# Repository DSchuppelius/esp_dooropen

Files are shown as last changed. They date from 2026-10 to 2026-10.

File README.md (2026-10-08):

# esp_dooropen

SIP-Türöffner für **ESP32 DevKit (WROOM-32)**, **WT32-ETH01** (ESP32 mit Ethernet) oder
**ESP8266 HW-364A** (NodeMCU mit fest verbautem OLED). Klingelt es, ruft der ESP per SIP ein Telefon an; mit **`*`** (oder einem Code) am
Telefon, über die **Weboberfläche**, per **Taster** oder aus **Home Assistant** wird die
Tür geöffnet.

Die Zielplattform wird über die PlatformIO-Umgebung gewählt (siehe
[Bauen & Flashen](#bauen--flashen-platformio)); der Code passt sich per
Präprozessor-Weiche automatisch an.

## Funktionen

- **Klingel-Eingang** (potentialfreier Kontakt, entprellt) mit Zähler und Hinweis
  „Es klingelt!“ im Web, auf dem Display und in Home Assistant.
- **Türsummer** über ein Relais, Dauer einstellbar (1–30 s). Ein Hardware-Timer
  schaltet das Relais auch dann pünktlich ab, wenn das Programm gerade hängt.
- **SIP-Anruf beim Klingeln** (getestet mit Asterisk, REGISTER mit Digest-Auth
  inkl. `qop=auth`/`opaque`, auch LANCOM-kompatibel):
  - **Rufkette**: mehrere Nummern nacheinander (z. B. `100, 101`), bis jemand abhebt,
  - nach dem Abheben ein Piepton im Hörer (G.711 A-law/µ-law),
  - **`*` am Telefon** (DTMF per RFC 4733 oder SIP INFO) öffnet die Tür und legt auf –
    oder ein **Öffnen-Code** (z. B. `1234`), dann bleibt das Gespräch 30 s offen,
  - wird nicht abgehoben, wird der Anruf nach 15 s per `CANCEL` zurückgezogen,
  - **SIP-Status im Klartext** und Ergebnis des letzten Anrufs,
  - **robust im WLAN**: `INVITE` (auch mit Digest), `CANCEL`, `BYE` und `REGISTER`
    werden bei Paketverlust wiederholt (RFC 3261); eine gescheiterte Erneuerung
    meldet erst „abgemeldet“, wenn die Anmeldung wirklich abläuft. Kopfzeilen in
    jeder Schreibweise und Kurzform (`i:`, `f:` …) werden verstanden; ein Server als
    Hostname wird einmal je Anmeldung aufgelöst (folgt auch einem DHCP-Wechsel).
- **Klingeln per Anruf**: Eine TK-Anlage (z. B. OpenCom) ruft beim Klingeln den
  Türöffner an – er nimmt nicht ab und wertet das als Klingeln. Ganz ohne Verdrahtung.
- **Anrufe an den Türöffner** (optional): Wer die Nebenstelle des Türöffners anruft,
  hört einen kurzen Ton und tippt den Öffnen-Code oder einen **Gästecode**
  (bis zu 5, mit Name, Ablaufdatum und „einmalig“). Nach mehreren falschen Codes
  werden Anrufe für 15 min gesperrt.
- **Weboberfläche** mit hellem/dunklem Design, großem Öffnen-Knopf mit
  Countdown-Ring, Statuskacheln, Test-Anruf und Ton-Benachrichtigung im Browser.
- **Home Assistant** per MQTT mit Auto-Discovery (Schloss, Button, Klingel-Ereignis,
  Sensoren, letztes Ereignis, Einstellungen).
- **OLED SSD1306** (optional) zeigt IP, Signal- und Summer-Status; wird kein
  Display gefunden, läuft alles ohne.
- **Status-LED** mit Blinkmustern (Summer, WLAN-Einrichtung, kein WLAN, SIP fehlt).
- **Taster** vor Ort: Klingel-Taster (wirkt wie Klingeln) und Summer-Taster (öffnet).
- **Zweites Relais** (Tor, Garage, zweite Tür) mit eigenem Knopf, eigener Dauer und
  wahlweise auch für den Tür-Zugang.
- **Tastenfeld / RFID-Leser** (Wiegand, ESP32): Öffnen-Code oder Gästecode am
  Tastenfeld, Karten/Chips mit Namen; Sperre nach Fehlversuchen.
- **Telegram-Bot** (ESP32): Klingel-Mitteilung mit Knopf **„Öffnen“**, Befehle
  `/status` und `/oeffnen` – auch unterwegs, ohne Portfreigabe.
- **Apple Home** (HomeKit, eigene ESP32-Variante): Türschloss mit Türklingel direkt in
  der Home-App, ohne Home Assistant.
- **Zugänge** mit eigener Anmeldeseite: Admin (alles) und Tür-Zugang (nur öffnen und
  Verlauf sehen, z. B. für den Kunden; ohne Tür-Passwort ist die Tür offen), dazu bis
  zu 8 **weitere Benutzer** mit Rolle und Zeitfenster – der Verlauf zeigt, wer
  geöffnet hat. Ohne Admin-Passwort warnt die Oberfläche deutlich.
- **Firmware-Update über WLAN**: per Browser-Upload oder aus PlatformIO (OTA, nur
  mit Admin-Passwort).
- **Erreichbar unter `http://tueroeffner.local`** (mDNS).
- **Verlauf** der letzten 30 Ereignisse mit Uhrzeit (NTP) und Detail (z. B. Name des
  Gästecodes, Nummer des Anrufers, Benutzer); **übersteht Neustarts**. Dazu ein langer
  Verlauf (mehrere Tausend Einträge) im Flash, als **CSV** herunterladbar.
- **Nachtruhe**: in einem Zeitfenster beim Klingeln nicht anrufen.
- **Praxis-Modus**: an gewählten Wochentagen in **zwei Zeitfenstern** öffnet Klingeln
  die Tür automatisch (ohne Anruf); **gesetzliche Feiertage je Bundesland** werden
  automatisch berücksichtigt, weitere **Ausnahmetage** (Urlaub) einstellbar. Bei
  Fenstern über Mitternacht (z. B. 22–2 Uhr) gehört der Teil nach Mitternacht zum
  Vortag (Wochentag, Feier- und Ausnahmetag des Vortags).
- **Uhrzeit** per NTP: `pool.ntp.org`, ersatzweise das **Gateway** (Router oder
  TK-Anlage, z. B. FRITZ!Box „Zeitserver im Heimnetz bereitstellen“) und
  `de.pool.ntp.org`. So laufen Praxis-Modus, Nachtruhe und Zeitfenster auch ohne
  Internet, wenn der Router NTP anbietet. Ohne gültige Uhrzeit sind Praxis-Modus und
  Nachtruhe aus.
- **Türkontakt** (Reed): Tür offen/zu im Web und in Home Assistant, Meldung, wenn die
  Tür zu lange offen steht, und Prüfung, ob nach dem Summer wirklich jemand
  hereinkam („Tür nach Summer geöffnet“ / „Summer, Tür blieb zu“).
- **Push-Mitteilungen ohne Home Assistant** über **ntfy** oder **Telegram**
  (Klingeln, Öffnen, Tür zu lange offen, Sperre nach falschen Codes).
- **Syslog**: Meldungen und Ereignisse an einen Syslog-Server (Fehlersuche aus der Ferne).
- **Ethernet** statt WLAN mit dem WT32-ETH01 (z. B. per PoE versorgt).
- **Selbstheilung**: Ist das WLAN weg, verbindet der ESP jede Minute neu; als letzte
  Stufe Neustart nach 30 min. Ethernet: Neustart nur, wenn ein Link da ist, aber
  10 min keine IP kommt (bei gezogenem Kabel nicht). Außerdem Neustart, wenn der
  Speicher knapp oder zerstückelt ist oder das Programm hängt (Watchdog auf beiden
  Boards); der Grund des letzten Starts wird angezeigt.
- **Neue IP per DHCP** wird erkannt, SIP meldet sich dann sofort neu an.
- **Sicherung**: alle Einstellungen als Datei herunterladen und wieder einspielen.
- **Feste IP-Adresse** wahlweise statt DHCP (vor dem Speichern geprüft: Maske,
  Gateway im selben Netz, keine Netz-/Broadcast-Adresse – gegen Aussperren).
- **Sperre gegen Sturmklingeln**: Klingeln innerhalb von 5 s löst keinen neuen
  Anruf aus.
- **WiFiManager**: Ohne gespeicherte Zugangsdaten öffnet der ESP das
  passwortgeschützte WLAN `Tueroeffner-Setup` zum Eintragen – **ohne zu blockieren**:
  Klingel, Taster und Summer funktionieren währenddessen weiter. Ist das bekannte WLAN
  nur weg (z. B. startet der Router nach einem Stromausfall langsamer als der ESP),
  verbindet er weiter und öffnet die Einrichtung erst nach 15 min ohne Verbindung –
  dann für 5 min, während die Verbindung zum WLAN weiter versucht wird.
- Einstellungen, Zähler und Verlauf liegen im **LittleFS** (Zähler/Verlauf werden
  höchstens alle 5 min geschrieben, der lange Verlauf gebündelt höchstens einmal pro
  Minute, um den Flash zu schonen; vor Neustart und Update wird alles gesichert).
  Gespeichert wird geprüft über eine Hilfsdatei – bei vollem oder defektem Speicher
  bleibt die alte Datei, die Oberfläche meldet den Fehler. Für die Einstellungen bleibt
  immer Platz frei (notfalls wird der ältere Verlauf gelöscht). Wurde der Speicher beim
  Start formatiert oder ist er nicht verfügbar, zeigt die Oberfläche eine Warnung.
  Ereignisse ohne Uhrzeit (kein NTP) bleiben erhalten und erscheinen als „ohne Uhrzeit“.

## Verdrahtung

### ESP32 DevKit (WROOM-32)

Hier gelten echte GPIO-Nummern. Ein OLED ist optional.

| Funktion | Pin | Hinweis |
|---|---|---|
| Relais S (Signal) | GPIO26 | schaltet das Relais (active-high) |
| Relais + / - | 5V / GND | Relais-Modul aus 5 V versorgen |
| Klingel-Kontakt | GPIO27 | eine Ader hier, andere Ader an GND |
| Klingel-Taster | GPIO32 | Taster gegen GND, wirkt wie Klingeln |
| Summer-Taster | GPIO33 | Taster gegen GND, öffnet die Tür |
| Türkontakt (optional)| GPIO25 | Reed-Kontakt gegen GND, geschlossen = zu |
| Status-LED | GPIO2 | onboard oder extern, siehe [Status-LED](#status-led) |
| OLED SDA (optional)  | GPIO21 | nur falls ein Display genutzt wird |
| OLED SCL (optional)  | GPIO22 | nur falls ein Display genutzt wird |
| Relais 2 (optional)  | GPIO13 | zweites Relais (Tor, Garage …) |
| Wiegand D0 (optional)| GPIO18 | Tastenfeld/RFID-Leser, siehe unten |
| Wiegand D1 (optional)| GPIO19 | Tastenfeld/RFID-Leser, siehe unten |

### ESP8266 HW-364A

Das OLED ist auf dem HW-364A **fest verdrahtet** an D5/D6.

| Funktion | Pin | Hinweis |
|---|---|---|
| OLED SDA (onboard)  | D5 (GPIO14) | fest verbaut, nicht belegen |
| OLED SCL (onboard)  | D6 (GPIO12) | fest verbaut, nicht belegen |
| KY-019 S (Signal) | D1 (GPIO5)  | schaltet das Relais (active-high) |
| KY-019 + (VCC) | 5V / VU | 5 V vom USB-Pin (nicht 3V3!) |
| KY-019 - (GND) | G | gemeinsame Masse |
| Klingel-Kontakt | D2 (GPIO4)  | eine Ader hier, andere Ader an GND |
| Klingel-Taster | D7 (GPIO13) | Taster gegen GND, wirkt wie Klingeln |
| Summer-Taster | D3 (GPIO0)  | gegen GND; Boot-Pin, nicht beim Start |
| Türkontakt (opt.) | RX (GPIO3)  | Reed gegen GND; beim USB-Flashen offen |
| Relais 2 (opt.) | D0 (GPIO16) | zweites Relais (Tor, Garage …) |

Tastenfeld/RFID (Wiegand) gibt es auf dem ESP8266 nicht – dafür sind keine Pins frei.

**Summer-Taster an D3 (GPIO0):** GPIO0 entscheidet beim Start, ob der ESP8266 normal
startet oder auf eine neue Firmware wartet. Ist der Taster beim Einschalten **oder bei
einem Neustart** (Update, Selbstheilung, Watchdog) gedrückt – oder klemmt er bzw. ist
die Leitung feucht –, bleibt der ESP im Flash-Modus hängen, bis er stromlos war. Die
Firmware kann das nicht abfangen. Für Dauerbetrieb daher ESP32 bzw. die Steuerplatine
nutzen oder den Taster so montieren, dass er nicht klemmen kann.

### WT32-ETH01 (Ethernet)

Umgebung `wt32-eth01`. Netzwerk über das eingebaute LAN8720 (kein WLAN, keine
WLAN-Einrichtung; feste IP wie gewohnt in der Weboberfläche). IO35/IO36/IO39 sind
reine Eingänge **ohne** internen Pull-up.

| Funktion | Pin | Hinweis |
|---|---|---|
| Relais (Summer) | IO4 | active-high |
| Klingel-Kontakt | IO32  | gegen GND |
| Klingel-Taster | IO33  | gegen GND |
| Summer-Taster | IO12  | gegen GND (Strapping-Pin: nie auf 3,3 V ziehen) |
| Türkontakt | IO2 | gegen GND |
| Status-LED | IO17  | LED mit 330 Ω gegen GND |
| Relais 2 | IO5 | Strapping-Pin, siehe Relais beim Start |
| Wiegand D0 / D1 | IO35 / IO36 | Pull-up bzw. Pegelwandler nötig |
| OLED SDA / SCL | IO15 / IO14 | optional |

### Relais beim Start

Die Firmware setzt die Relais als allererstes in Ruhelage. Davor – während Reset,
Bootloader und Programmstart (einige 100 ms) – bestimmt die Hardware den Pegel:

| Board | Relais 2 | Pegel beim Start | Risiko |
| --- | --- | --- | --- |
| ESP32 DevKit / [Steuerplatine](hardware/README.md) | GPIO13 | kein Pull-up | keins (Platine: 100 kΩ hält das Gate auf GND) |
| WT32-ETH01 | IO5 | interner **Pull-up** (Strapping-Pin) | active-high-Modul kann kurz anziehen |
| ESP8266 | D0 (GPIO16) | beim Start **HIGH** | active-high-Modul kann kurz anziehen |

Relais 1 (Summer: GPIO26, IO4, D1/GPIO5) ist davon nicht betroffen. Hängt an Relais 2
etwas, das schon ein kurzer Impuls auslöst (Tor, Garage):

- **WT32-ETH01:** einen **Pull-down von 4,7–10 kΩ** vom Relais-Eingang (IN/S) nach GND
  einbauen – stärker als der interne Pull-up; IO5 darf beim Start LOW sein (betrifft
  nur das SDIO-Timing).
- **WT32-ETH01 und ESP8266:** ein Relais-Modul nehmen, das bei **LOW** schaltet, und in
  [src/config.h](src/config.h) `RELAY2_ACTIVE_LOW` auf `true` setzen – der HIGH-Pegel
  beim Start bedeutet dann „aus“.

### Tastenfeld / RFID-Leser (Wiegand)

Viele Zutritts-Tastenfelder und Kartenleser haben eine **Wiegand-Schnittstelle**
(Leitungen D0, D1, GND). Erkannt werden Tastendrücke (4 bzw. 8 Bit) und Karten
(26 Bit mit Parität, 34 Bit).

```text
Leser D0 (grün) ──[Pegelwandler]── GPIO18     Leser GND ── GND
Leser D1 (weiß) ──[Pegelwandler]── GPIO19     Leser +12 V ── eigenes Netzteil
```

Die meisten Leser ziehen D0/D1 auf **5 V** hoch – das verträgt der ESP32 nicht. Dann
einen **Pegelwandler** (z. B. BSS138-Modul) oder je Leitung einen Spannungsteiler
(z. B. 10 kΩ / 20 kΩ) dazwischen. Leser mit Open-Collector-Ausgang können direkt an
die Pins (der ESP schaltet den internen Pull-up ein).

Bedienung am Tastenfeld: Code eintippen, **#** bestätigt, ***** löscht. Gültig sind
Öffnen-Code und Gästecodes. Karten werden unter **Einstellungen → Tastenfeld / RFID**
angelernt: Karte an den Leser halten, die Nummer erscheint dort zum Übernehmen.

### Türöffner und Klingel

Der Türöffner hängt am **Relaiskontakt** (COM + NO) zusammen mit einem
**Klingeltrafo** (8–12 V AC): Trafo → COM, NO → Türöffner → zurück zum Trafo.

**Wichtig:**

- Der **Klingel-Eingang** verträgt nur einen *potentialfreien Kontakt* oder einen
  Optokoppler-Ausgang – **niemals die Klingelspannung direkt** (siehe
  [Klingel-Eingang anschließen](#klingel-eingang-anschließen)).
- Der **Summer** wird **nicht** vom ESP versorgt. Der ESP schaltet nur das Relais,
  der Summer hat seinen eigenen Stromkreis.
- Die Voreinstellung passt für das **KY-019** (schaltet bei HIGH). Für Relais-Module,
  die bei LOW schalten (viele blaue Module), in `src/config.h`
  `RELAY_ACTIVE_LOW` auf `true` setzen.

- **Zusätzliche Absicherung (empfohlen):** Das Relais wird per Hardware-Timer
  abgeschaltet, auch wenn das Programm hängt. Gegen einen *Defekt* des ESP (Pin bleibt
  auf HIGH) hilft das nicht. Wer das ausschließen will, schaltet den Türöffner über ein
  **Zeitrelais/Monoflop** (z. B. NE555-Schaltung oder fertiges „Delay Off“-Modul mit
  max. 30 s), das der ESP nur anstößt.

### Klingel-Eingang anschließen

Der Klingel-Eingang (ESP32: **GPIO27**, ESP8266: **D2**) arbeitet mit internem Pull-up:
**aktiv = gegen GND gezogen**. Erkannt werden sowohl Dauersignale als auch mit 50 Hz
pulsierende Signale (Optokoppler an Wechselspannung) – das Signal gilt als aktiv,
solange es in den letzten 40 ms aktiv war (`SIGNAL_AC_HOLD_MS`).

Gegen Störungen: Das Signal allein braucht mindestens 3 aktive Abtastungen
(`SIGNAL_MIN_SAMPLES`), und solange der Summer an ist sowie 300 ms danach zählt
Klingeln nicht (`RING_BUZZER_GUARD_MS`, Einkopplung vom Türöffner). Ein Eingang, der
schon beim Start aktiv ist (klemmender Taster, Feuchte), zählt erst, nachdem er einmal
frei war – das gilt auch für den Summer-Taster. Hängt das Programm kurz (Netzwerk,
Flash), erkennt ein Interrupt Tastendrücke ab 50 ms trotzdem und holt sie nach.

Welche Variante passt?

| Was ist vorhanden? | Variante |
| --- | --- |
| freier Schaltkontakt (Relaisausgang einer Sprechanlage, zweiter Kontakt am Taster) | **A** – direkt |
| klassische Klingel mit Klingeltrafo (8–12 V~) und Gong | **B** – Optokoppler parallel zum Gong |
| Klingeltaster an einer **TK-Anlage** (Sensor-Eingang, z. B. Aastra/Mitel OpenCom) | **C** – Optokoppler parallel zum Sensor |
| Klingel mit Gleichspannung (z. B. 12 V⎓) | **D** – Optokoppler, Polung beachten |
| Bus-Sprechanlage (2-Draht: Siedle, Ritto, Busch-Jaeger, TCS …) | **E** – über deren Schaltaktor |

**Vorher messen:** Messgerät auf **V~** (bei D auf V⎓), an die beiden Adern halten und
klingeln lassen. In Ruhe ~0 V, beim Klingeln die Klingelspannung → Variante B/C/D.
Liegt schon *ohne* Klingeln eine Spannung an (z. B. 15–30 V⎓) und ändert sich beim
Drücken nur wenig, ist es vermutlich ein Bus (E). Auf Gleichspannung gemessen zeigt
eine Wechselspannung nur wackelige Werte nahe 0 V.

#### A) Potentialfreier Kontakt

Der Kontakt hat keine eigene Spannung (nur „zu“ oder „offen“) – direkt anschließen:

```text
Kontakt ──── GPIO27 (ESP8266: D2)
Kontakt ──── GND
```

Keine weiteren Bauteile. Gilt genauso für den Klingel-Taster am Gerät selbst
(GPIO32 / D7).

#### B) Klingeltrafo und Gong (Wechselspannung)

Der Optokoppler kommt **parallel zum Gong** (an dessen zwei Klemmen): Nur beim
Klingeln liegt dort Spannung an. Der Gong klingelt weiter wie bisher.

```text
Gong-Klemme 1 ──[ Vorwiderstand ]──┬──── IN+  (Optokoppler-Modul)
                                   │
                                1N4148   (Strich/Kathode zu IN+)
                                   │
Gong-Klemme 2 ─────────────────────┴──── IN−
```

- **Zusätzlicher Vorwiderstand** ist nötig, auch wenn das Modul schon einen hat (der
  ist meist für 3–5 V⎓ ausgelegt, z. B. 330 Ω, Aufdruck `331`). Bei Wechselspannung
  zählt die Spitze (≈ 1,4 × Nennwert).
- **Diode 1N4148 antiparallel** ist Pflicht: In der negativen Halbwelle läge sonst die
  volle Spannung rückwärts an der LED im Optokoppler (PC817 verträgt nur 6 V).

| Klingelspannung | Spitze | zusätzlicher Vorwiderstand | LED-Strom (mit 330 Ω auf dem Modul) |
| --- | --- | --- | --- |
| 6–8 V~  | 8–11 V  | 680 Ω – 1 kΩ  | ~6–10 mA |
| 12 V~ | 17 V | **1 kΩ** | ~12 mA |
| 24 V~ | 34 V | **2,2 kΩ** | ~14 mA |

¼-W-Widerstände reichen. **1 kΩ deckt 6–12 V~ sicher ab.** Nicht parallel zum
*Taster* anschließen: Dort liegt die Spannung in Ruhe an, beim Drücken nicht – das
wird nicht unterstützt und belastet den Gong dauerhaft.

#### C) Sensor-Eingang einer TK-Anlage (z. B. OpenCom 130/131/150 mit TFE-Karte)

Hier schaltet der Klingeltaster die Wechselspannung eines Klingeltrafos auf den
Sensor-Eingang der Anlage (OpenCom M100-TFE/TFE-2: Sensor für 6–24 V~). Die Anlage ruft
daraufhin die eingestellten Telefone an.

Den Optokoppler **parallel zum Sensor-Eingang** anschließen – an die beiden Adern, die
auf die Sensor-Klemme der Anlage gehen (bei RJ45-Verkabelung das entsprechende
Aderpaar). Beschaltung wie bei **B** (Vorwiderstand + 1N4148). Die Anlage merkt davon
nichts, der Optokoppler zieht nur ~10 mA aus dem Klingeltrafo.

Gegenprobe auf **V~** an diesen Adern: in Ruhe ~0 V, beim Klingeln 6–24 V~.

**Alternative ganz ohne Verdrahtung:** Die Anlage ruft beim Klingeln den Türöffner an –
siehe [Klingeln per Anruf](#klingeln-per-anruf-tk-anlage).

#### D) Klingel mit Gleichspannung

Wie **B**, aber auf die Polung achten: Plus über den Vorwiderstand an `IN+`, Minus an
`IN−`. Die 1N4148 schützt bei vertauschter Polung (dann wird nur nichts erkannt).
Vorwiderstand nach der Gleichspannung (ohne Faktor 1,4): 12 V⎓ → 680 Ω – 1 kΩ,
24 V⎓ → 2,2 kΩ.

#### E) Bus-Sprechanlage

Die Adern führen Versorgung und Daten gemeinsam – ein Optokoppler erkennt dort das
Klingeln nicht zuverlässig und kann den Bus stören. Stattdessen den **Schaltaktor /
Relaisausgang** der Anlage (bei den meisten Herstellern als Zusatzmodul, Funktion
„Etagenruf/Türruf schaltet Kontakt“) als potentialfreien Kontakt nutzen → Variante **A**.

#### Ausgangsseite des Optokoppler-Moduls (B, C, D)

| Modul | ESP32 | ESP8266 (HW-364A) |
| --- | --- | --- |
| VCC | **3V3** (nicht 5 V!) | 3V3 |
| GND | GND | G |
| OUT | GPIO27 | D2 (GPIO4) |

**VCC immer an 3,3 V:** Der Ausgang wird auf dem Modul meist auf VCC hochgezogen – an
5 V lägen 5 V am ESP-Eingang (verträgt nur 3,3 V). Hat das Modul ausgangsseitig nur
zwei Anschlüsse (Kollektor/Emitter): Kollektor an GPIO27, Emitter an GND; den Pull-up
hat der ESP intern.

Logik: Klingeln → Optokoppler leitet → `OUT` = LOW → passt zu `SIGNAL_ACTIVE_LOW true`
in [src/config.h](src/config.h) (Voreinstellung, nichts ändern).

**Test:** In der Weboberfläche zeigt die Kachel *Signal* beim Klingeln „aktiv“, darüber
erscheint „Es klingelt!“ und im Verlauf „🔔 Klingeln“.

### Status-LED

| Muster | Bedeutung |
|---|---|
| dauerhaft an | Summer schaltet |
| schnelles Blinken | WLAN-Einrichtung (`Tueroeffner-Setup`) offen |
| langsames Blinken | kein WLAN |
| kurzer Blitz alle 2 s | SIP nicht angemeldet |
| aus | alles in Ordnung |

**Keine Onboard-LED?** Nicht jedes ESP32-DevKit hat eine schaltbare LED an GPIO2
(meist blau). Die **rote LED** ist bei vielen Boards nur die Betriebs-LED – sie hängt
fest an 3,3 V, leuchtet immer und lässt sich nicht ansteuern (flackert höchstens kurz,
wenn das Relais anzieht). Dann einfach eine **externe LED** anschließen:

```text
GPIO2 ──[ 330 Ω ]──►|── GND      (langes Bein = Anode zu GPIO2)
```

Die Firmware muss dafür nicht geändert werden. Soll die LED an einem anderen Pin
hängen, `PIN_STATUS_LED` (und ggf. `STATUS_LED_ACTIVE_LOW`) in
[src/config.h](src/config.h) anpassen. Ohne LED funktioniert alles genauso – den
Zustand zeigen dann Weboberfläche und Home Assistant.

Alle Pins stehen in [src/config.h](src/config.h) und lassen sich dort anpassen.

## Bauen & Flashen (PlatformIO)

```powershell
pio run -e esp32dev         -t upload   # ESP32 DevKit
pio run -e esp32dev_homekit -t upload   # ESP32 DevKit mit Apple Home
pio run -e wt32-eth01       -t upload   # WT32-ETH01 (Ethernet)
pio run -e nodemcuv2        -t upload   # ESP8266 HW-364A

pio device monitor -b 115200            # serielle Ausgabe
```

| Umgebung | Board | Besonderheit |
|---|---|---|
| `esp32dev` | ESP32 DevKit | alle Funktionen außer Apple Home |
| `esp32dev_homekit` | ESP32 DevKit | zusätzlich Apple Home (Programmspeicher ~97 % voll) |
| `wt32-eth01` | WT32-ETH01 | Ethernet statt WLAN |
| `nodemcuv2` | ESP8266 | ohne Telegram-Bot, Tastenfeld/RFID und Apple Home  |

Apple Home ist eine eigene Variante, weil die Bibliothek HomeSpan rund 400 KB belegt
und schon beim Start in die WLAN-Einstellungen eingreift.

**ESP32-Flashen:** Manche ESP32-Boards wechseln nicht automatisch in den
Download-Modus (`Wrong boot mode detected (0x13)` bzw. `No serial data received`).
Dann manuell: **BOOT** gedrückt halten → **EN/RST** kurz drücken → **BOOT**
loslassen, danach den Upload starten. Die Umgebung `esp32dev` ist mit
`board_upload.before_reset = no_reset` dafür vorbereitet.

**Weboberfläche:** Die Seite liegt in [src/web/index.html](src/web/index.html). Beim
Bauen bettet [tools/embed_html.py](tools/embed_html.py) sie gzip-komprimiert als
`include/index_html.h` ein (automatisch, nicht einchecken).

**ESP32-Plattform:** `esp32dev` ist fest auf die offizielle
[pioarduino](https://github.com/pioarduino/platform-espressif32)-Plattform
(Arduino-Core 3.1.3) eingestellt. Die gleichnamige Tasmota-Variante enthält kein TLS,
das für Push-Mitteilungen (HTTPS) nötig ist. Die Flash-Aufteilung `min_spiffs.csv`
schafft Platz für die größere Firmware (2× 1,9 MB für OTA) und enthält 128 KB für
das LittleFS. **Wer von Version 1.2 kommt, muss einmal per USB flashen** – eine neue
Flash-Aufteilung lässt sich nicht per OTA übertragen. Die Einstellungen bleiben dabei
erhalten.

### Update auf Version 1.5

- Neue Einstellungen erscheinen mit ausgeschalteten Voreinstellungen – das Verhalten
  bleibt, bis man etwas aktiviert.
- Der lange Verlauf (CSV) beginnt mit dem Update; der bisherige kurze Verlauf bleibt.

### Update von Version 1.3

- Die Einstellungen wandern beim ersten Start automatisch aus dem EEPROM ins
  **LittleFS** – nichts weiter zu tun. Danach wird der alte EEPROM-Stand stillgelegt
  (er wird nie wieder geladen, auch nicht nach einem Formatieren des LittleFS); ein
  Zurück auf 1.3 beginnt deshalb mit Standardwerten.
- **OTA aus PlatformIO funktioniert nur noch mit Admin-Passwort.** In
  [platformio.ini](platformio.ini) bei `upload_flags = --auth=PASSWORT` das
  Admin-Passwort eintragen. Ohne Passwort: einmal per Browser-Upload aktualisieren.
- Das Einrichtungs-WLAN hat jetzt ein Passwort (Standard `tuer-einrichten`, im Web
  änderbar – bitte je Installation ändern).
- Die HTTP-API erwartet Parameter im **Body** (Formular), nicht mehr in der URL;
  Aufrufe von fremden Webseiten werden abgelehnt (siehe *Sicherheit*).

### Update über WLAN

Ab Version 1.2 ist kein USB-Kabel mehr nötig:

- **Browser:** Tab **System → Firmware-Update**, Datei
  `.pio/build/esp32dev/firmware.bin` (bzw. `nodemcuv2`) auswählen, hochladen.
- **PlatformIO:**

  ```powershell
  pio run -e esp32dev_ota  -t upload   # ESP32
  pio run -e nodemcuv2_ota -t upload   # ESP8266
  ```

  OTA ist nur aktiv, wenn ein Admin-Passwort gesetzt ist (danach einmal neu
  starten). In [platformio.ini](platformio.ini) bei `upload_flags = --auth=PASSWORT`
  das Passwort eintragen.

## Inbetriebnahme

1. Nach dem ersten Start mit dem WLAN `Tueroeffner-Setup` verbinden (Passwort
   `tuer-einrichten`, steht auch auf dem Display) und das Heim-WLAN eintragen.
2. Die IP-Adresse erscheint auf dem Display bzw. in der seriellen Ausgabe.
3. Im Browser die IP öffnen und unter **Einstellungen** eintragen:
   - **SIP-Zugang**: Server, Port, Benutzer, Passwort (eine eigene Nebenstelle für
     den Türöffner in der Telefonanlage anlegen),
   - **Türsummer & Anruf**: Dauer, Rufkette (z. B. `100, 101`), optional ein
     Öffnen-Code, Schalter „Beim Klingeln anrufen“.
4. Mit **Test-Anruf** prüfen: Telefon klingelt → abheben → Piepton → `*` (bzw. Code)
   drücken → Summer schaltet, Anruf endet.
5. Unter **System** ein **Admin-Passwort** setzen (die Oberfläche warnt, solange keins
   gesetzt ist), das Passwort der **WLAN-Einrichtung** ändern, bei Bedarf einen
   Tür-Passwort für den Kunden anlegen und eine **Sicherung** herunterladen.

## Weboberfläche

| Tab | Inhalt |
|---|---|
| **Tür** | Öffnen-Knopf, Status (SIP, Tür, Modus, letzter Anruf), Verlauf  |
| **Einstellungen**  | Summer, Rufkette, Code, Anrufe/Gästecodes, Nachtruhe, Praxis-Modus, Türkontakt, SIP |
| **Dienste** | Push-Mitteilungen (ntfy/Telegram), Home Assistant (MQTT), Syslog |
| **System** | Geräte-Info, Netzwerk, WLAN-Einrichtung, Zugänge, Sicherung, Firmware-Update |

**Anmeldung:** Die Oberfläche hat eine eigene Anmeldeseite (kein Browser-Fenster).
„Angemeldet bleiben“ hält die Anmeldung 30 Tage, auch über Neustarts des Geräts;
sonst bis zum Schließen des Browsers. Oben rechts stehen *Anmelden* / *Abmelden* und
mit wem man angemeldet ist.

| Admin-Passwort | Tür-Passwort | Tab „Tür“ (öffnen, Verlauf) | Einstellungen |
| --- | --- | --- | --- |
| – | – | offen | offen |
| gesetzt | – | **ohne Anmeldung** | Admin |
| gesetzt | gesetzt | Tür- oder Admin-Anmeldung | Admin |

Wechselt ein Passwort, werden die Anmeldungen der betroffenen Rolle beendet.

**Bedienung:**

- **Öffnen**: den Knopf **0,8 s gedrückt halten** (der Ring füllt sich) – kurzes
  Antippen öffnet nicht (Schutz vor versehentlichem Öffnen, z. B. in der Tasche).
  Mit der Tastatur (Enter/Leertaste) öffnet er sofort. Öffnen beendet auch einen
  gerade laufenden Anruf. Der Countdown startet erst, wenn das Gerät das Öffnen
  bestätigt hat; ein Fehler wird angezeigt.
- **Verlauf**: zeigt die neuesten 5 Einträge, aufklappbar; Filter *Klingeln*,
  *Öffnungen*, *Anrufe*.
- Beim Klingeln: Hinweis auf der Seite, Titel des Browser-Tabs „🔔 Es klingelt“,
  Vibration (Handy) und – nach einem Klick auf die Seite – ein Ton.
- Passwortfelder lassen sich per Auge-Symbol im Klartext anzeigen.
- Der geöffnete Tab steht in der Adresse (`#einstellungen`, `#system`, …) und
  bleibt beim Neuladen erhalten.
- Antwortet das Gerät nicht mehr, erscheint ein deutlicher Hinweis (nach 3 s ohne
  Antwort gilt die Anzeige als veraltet; Anfragen brechen nach 4 s ab).
- Auf dem Handy über „Zum Startbildschirm hinzufügen“ wie eine App nutzbar.

### HTTP-API

Änderungen per `POST`, Parameter als Formular im Body (`application/x-www-form-urlencoded`).

| Methode | Pfad | Parameter | Funktion |
|---|---|---|---|
| GET | `/status` | – | Live-Zustand als JSON |
| GET | `/config` | – | Einstellungen als JSON (Admin) |
| GET | `/log` | – | Verlauf als JSON |
| POST | `/api/login` | `user`, `pw`, `keep` (1 = 30 Tage) | Anmelden (setzt Sitzungs-Cookie) |
| POST | `/logout` | – | Abmelden |
| POST | `/open` | – | Tür öffnen |
| POST | `/open2` | – | zweites Relais schalten |
| GET | `/log.csv` | – | langer Verlauf als CSV |
| POST | `/call` | – | Test-Anruf |
| POST | `/setduration` | `s` | Summer-Dauer (Sekunden) |
| POST | `/setdial` | `nr`, `pin`, `auto`, `s` | Rufkette, Code, Dauer |
| POST | `/setincoming` | `on`, `guests` | Anrufe annehmen, Gästecodes (`Code:bisUnix:einmalig:Name;…`) |
| POST | `/setsip` | `server`, `port`, `user`, `pw` | SIP-Zugang |
| POST | `/setmqtt` | `server`, `port`, `user`, `pw` | MQTT-Broker |
| POST | `/setsyslog` | `server` | Syslog-Server |
| POST | `/setring` | `callers` (Liste, `*` = jeder) | Klingeln per Anruf |
| POST | `/setrelay2` | `on`, `name`, `dur`, `user` | zweites Relais |
| POST | `/setusers` | `users` (`Name:Passwort:Rolle:Tage:Von:Bis;…`, Felder %-kodiert, leeres Passwort = unverändert) | weitere Benutzer |
| POST | `/settelegram` | `open`, `chats` | Telegram-Bot |
| POST | `/setkeypad` | `on`, `cards` (`Nummer:Name;…`) | Tastenfeld / RFID |
| POST | `/sethomekit`  | `on`, `reset` (neuer Code) | Apple Home (nach Neustart)|
| POST | `/setquiet` | `on`, `from`, `to` (Minuten) | Nachtruhe |
| POST | `/setpraxis` | `on`, `days` (Bits Mo–So), `from`, `to`, `from2`, `to2`, `free`, `holiday` (z. B. `NW`) | Praxis-Modus |
| POST | `/setdoor` | `on`, `inv`, `alert` (Minuten) | Türkontakt |
| POST | `/setpush` | `type`, `server`, `topic`, `token`, `ev` | Push-Mitteilungen |
| POST | `/testpush` | – | Test-Mitteilung |
| POST | `/setweb` | `user`, `pw` oder `off=1` | Admin-Zugang |
| POST | `/setop` | `user`, `pw` oder `off=1` | Tür-Zugang |
| POST | `/setap` | `pw` (leer = offen) | Passwort WLAN-Einrichtung |
| POST | `/setnet` | `static`, `ip`, `mask`, `gw`, `dns` | Netzwerk (Neustart) |
| POST | `/resetcounters` | – | Zähler auf 0 |
| GET | `/backup` | – | Sicherung herunterladen |
| POST | `/restore` | Felder der Sicherung (Formular) | Sicherung einspielen |
| POST | `/restart` | – | Neustart |
| POST | `/wifireset` | – | WLAN-Daten löschen |
| POST | `/update` | Datei (multipart) | Firmware-Update |

Der Tür-Zugang darf nur `/status`, `/log`, `/log.csv`, `/open`, `/call` und – falls
freigegeben – `/open2`. Ohne Anmeldung
antwortet das Gerät mit `401` (ohne Browser-Anmeldefenster).

Werkzeuge können statt der Anmeldeseite **Basic-Auth** verwenden, z. B.:
`curl -X POST -u admin:PASSWORT http://tueroeffner.local/open`

### Tür per Desktop-Symbol (Windows, Linux)

Ein Symbol **„Tür öffnen“** auf dem Desktop – ein Klick öffnet die Tür (z. B. am
Empfang einer Praxis):

```powershell
# Windows
powershell -ExecutionPolicy Bypass -File tuer-oeffnen.ps1 -Install -Address 192.168.20.50
```

```bash
# Linux (GNOME, KDE, Xfce ...; braucht curl)
bash tuer-oeffnen.sh --install --address 192.168.20.50
```

Skripte: [tools/tuer-oeffnen.ps1](tools/tuer-oeffnen.ps1) bzw.
[tools/tuer-oeffnen.sh](tools/tuer-oeffnen.sh). Unter Linux erscheint der Starter im
Anwendungsmenü und – falls der Desktop Symbole zeigt – auf dem Desktop (GNOME braucht
dafür die Erweiterung „Desktop Icons NG“, sonst über das Menü bzw. als Favorit).

- Als Adresse am besten die **IP** des Türöffners (feste IP oder DHCP-Reservierung);
  `tueroeffner.local` wird nur im selben Subnetz aufgelöst.
- Ist ein Tür-Passwort gesetzt, fragt das Symbol beim ersten Mal nach Benutzer und
  Passwort und merkt sie sich: Windows verschlüsselt (DPAPI, nur dieser Windows-Benutzer
  auf diesem PC), Linux im Schlüsselbund (`secret-tool`) oder sonst in einer nur für
  den Benutzer lesbaren Datei. Für das Fenster unter Linux `zenity` oder `kdialog`.
  Dafür einen eigenen Benutzer anlegen (Tür-Zugang oder **Weitere Benutzer** mit Rolle
  Tür), nie den Admin.
- Mehrfaches Klicken öffnet nur einmal (verlängert höchstens die Summerzeit).
- Gespeicherte Anmeldung vergessen: `-Reset` bzw. `--reset` (mit derselben Adresse).
  Entfernen: Symbol löschen, dazu `%LOCALAPPDATA%\Tueroeffner` (Windows) bzw.
  `~/.local/share/tueroeffner` und `~/.local/share/applications/tueroeffner.desktop`
  (Linux).

## Sicherheit

- **Passwort setzen!** Ohne Admin-Passwort kann jeder im WLAN die Tür öffnen; die
  Oberfläche zeigt dann eine Warnung. Anmeldung über die eigene Anmeldeseite
  (Sitzungs-Cookie `HttpOnly`, `SameSite=Strict`) oder Basic-Auth für Werkzeuge. Die
  Übertragung ist unverschlüsselt – den ESP nur im eigenen Netz betreiben (kein
  Port-Forwarding).
- **Sperre nach falschen Anmeldungen**: nach 5 Fehlversuchen wird die Adresse 60 s
  gesperrt, bei weiteren Fehlern länger (bis 15 min).
- **Schutz vor fremden Webseiten (CSRF)**: Änderungen werden nur von der eigenen Seite
  angenommen (`Origin`/`Sec-Fetch-Site`). `curl` & Co. ohne `Origin` funktionieren
  weiter. Ohne Passwort ist die Oberfläche zudem nur über IP-Adresse oder
  `tueroeffner(.local)` erreichbar (Schutz vor DNS-Rebinding).
- **SIP**: Anfragen (Anrufe, DTMF per INFO) werden nur von der Telefonanlage
  angenommen, DTMF-Töne per RTP nur von der Gegenstelle des Gesprächs oder der Anlage.
- **Home Assistant**: „Tür öffnen“ reagiert nur auf `PRESS`/`OPEN`/`UNLOCK`; Befehle
  direkt nach dem Verbinden und gespeicherte (*retained*) Befehle werden ignoriert
  bzw. gelöscht (noch vor dem Abonnieren) – eine versehentlich gespeicherte Nachricht
  öffnet also nicht bei jedem Neustart die Tür.
- **Telegram**: Ein „Öffnen“-Knopf gilt nur kurz und nur bis zum nächsten Neustart;
  Nachrichten, die vor dem Start eingingen, werden verworfen.
- **OTA** aus PlatformIO nur mit Admin-Passwort; das WLAN-Einrichtungsportal bietet
  keinen Firmware-Upload an.
- **Notfall-Reset:** Klingel-Taster beim Einschalten (oder nach der Reset-Taste)
  5 s gedrückt halten, bis „Jetzt loslassen“ erscheint, und **loslassen** – dann sind
  beide Passwörter gelöscht und das Gerät nutzt wieder DHCP statt einer festen IP.
  Nach einem Neustart per Software oder Watchdog wirkt der Taster nicht, ein
  dauerhaft gedrückter (klemmender) Taster löst nie aus. Der Reset steht im Verlauf
  („Gerät gestartet – Notfall-Reset“) und wird per Push gemeldet. Den Klingel-Taster
  trotzdem **nicht von außen zugänglich** montieren.

## Anrufe an den Türöffner und Gästecodes

Unter **Einstellungen → Anrufe an den Türöffner** einschalten. Ruft jemand die
Nebenstelle des Türöffners (SIP-Benutzer) an, nimmt der ESP an, spielt einen kurzen
Ton und wartet 30 s auf einen Code:

- den **Öffnen-Code** (wie beim Rückruf) oder
- einen **Gästecode**: bis zu 5 Stück mit Name, optionalem Ablaufdatum und
  „einmalig“ (wird nach dem Öffnen gelöscht) – z. B. für Paketdienst oder Handwerker.

`*` oder `#` löscht die Eingabe. Nach 3 falschen Codes legt der ESP auf; nach 6 falschen
Codes innerhalb von 15 min werden Anrufe 15 min lang abgelehnt (mit Push-Meldung).
Ohne Öffnen-Code und ohne gültigen Gästecode werden keine Anrufe angenommen.
Klingelt es während eines solchen Anrufs, hat die Klingel Vorrang: der Anruf wird
beendet und die Rufkette startet, sobald die Leitung frei ist.

## Klingeln per Anruf (TK-Anlage)

Statt das Klingelsignal zu verdrahten, kann die Telefonanlage den Türöffner beim
Klingeln **anrufen** – genau wie sie die Telefone anruft. Unter **Einstellungen →
Klingeln per Anruf** die Nummer(n) eintragen, von denen solche Anrufe kommen (`*` =
jeder Anrufer). Der Türöffner nimmt diese Anrufe nicht an (Antwort „486 Besetzt“, damit
die Anlage die übrigen Telefone weiter klingeln lässt) und wertet sie als Klingeln:
Verlauf, Push, Home Assistant, Praxis-Modus – alles wie beim Klingelkontakt.

Einrichten, z. B. OpenCom: in der Anlage beim Türklingel-Sensor die Nebenstelle des
Türöffners als (zusätzliches) Ziel eintragen, einmal klingeln, dann in der
Weboberfläche bei „Letzter Anrufer“ auf **Übernehmen** klicken. Damit der Türöffner
nicht zusätzlich selbst anruft, „Beim Klingeln anrufen“ ausschalten, wenn die Anlage
die Telefone schon klingeln lässt.

## Weitere Benutzer

Unter **System → Weitere Benutzer** bis zu 8 Personen mit eigenem Namen und Passwort
anlegen – Rolle **Tür** (öffnen, Verlauf) oder **Admin**. Optional mit Zeitfenster
(Wochentage, Uhrzeit), z. B. „Reinigung: Mo–Fr 6–9 Uhr“. Außerhalb des Fensters ist
keine Anmeldung möglich und bestehende Anmeldungen ruhen. Im Verlauf steht, wer
geöffnet hat (z. B. „Geöffnet (Web) – Anna“).

## Push-Mitteilungen

Unter **Dienste → Push-Mitteilungen**:

- **ntfy**: App „ntfy“ installieren, ein schwer erratbares Topic abonnieren (z. B.
  `tuer-k7x2p9`) und dasselbe Topic eintragen. Eigener ntfy-Server und Zugangs-Token
  sind möglich.
- **Telegram**: Bot über `@BotFather` anlegen, Bot-Token und Chat-ID eintragen.

Auf dem ESP8266 hat jede Mitteilung ein festes Zeitbudget von 5 s (Namensauflösung
höchstens 2 s). Ist der Server nicht auflösbar oder für HTTPS zu wenig Speicher frei
(BearSSL braucht 16 KB am Stück), wird sie übersprungen und das im Log vermerkt. Bis zu
3 Mitteilungen warten; ist die Warteschlange voll, fällt die älteste weg (ebenfalls im
Log, auf dem ESP32 bei mehr als 4 wartenden).

Zusätzlich wählbar: **„Melden, wenn nach dem Summer niemand hereinkam“** (braucht den
Türkontakt).

### Telegram-Bot (ESP32)

Ist Telegram eingestellt, beantwortet der Türöffner auch Nachrichten:

| Befehl | Funktion |
|---|---|
| `/status` | Zustand (SIP, Zähler, Tür, Modus, letztes Ereignis) |
| `/oeffnen` | Rückfrage mit Knopf **„Jetzt öffnen“** |

Mit **„Öffnen per Telegram erlauben“** bekommen Klingel-Mitteilungen einen Knopf
**„🔓 Öffnen“**. Ein Knopf gilt 3 Minuten und nur bis zum nächsten Neustart – alte
Mitteilungen öffnen später nicht mehr. Nachrichten, die vor dem Start eingingen,
verwirft der Bot.
Nur die eingetragene Chat-ID und die **weiteren erlaubten Chat-IDs** dürfen den Bot
benutzen; ein fremder Chat bekommt seine Chat-ID angezeigt (zum Freischalten). Der Bot
fragt per Long-Polling bei Telegram nach – keine Portfreigabe nötig. Auf dem ESP8266
nicht verfügbar (zu wenig Speicher für die dauernde TLS-Verbindung).

Wählbar sind Meldungen bei Klingeln, Öffnen und „Tür zu lange offen“; die Sperre nach
falschen Codes wird immer gemeldet. Auf dem ESP32 laufen sie in einem eigenen Task und
prüfen das Server-Zertifikat. Auf dem ESP8266 werden sie erst nach dem Anruf bzw. der
Rufkette gesendet (der Anruf hat Vorrang), nicht während der Summer läuft, und ohne
Zertifikatsprüfung.

## Syslog

Unter **Dienste → Syslog** einen Server eintragen (UDP 514, z. B. rsyslog, Synology
Log Center oder das Home-Assistant-Add-on). Der ESP schickt dann alle Meldungen
(Start, WLAN, SIP-Anmeldung, Gespräche, MQTT, Ereignisse) dorthin – ideal zur Fehlersuche bei
einer Kundeninstallation. Codes und Passwörter werden nicht übertragen.

## Apple Home (HomeKit)

Variante `esp32dev_homekit` flashen, dann unter **Dienste → Apple Home** einschalten
und neu starten. In der Home-App: **Gerät hinzufügen → Weitere Optionen →
Türöffner** und den angezeigten Kopplungscode eingeben.

- **Türschloss**: „Aufschließen“ löst den Summer aus; das Schloss zeigt „offen“,
  solange der Summer läuft.
- **Türklingel**: Klingeln erzeugt eine Mitteilung auf iPhone, Watch und HomePod.

HomeSpan nutzt das WLAN des Türöffners und den Port 1201; `tueroeffner.local` und die
Weboberfläche bleiben unverändert. Ein- und Ausschalten wirkt nach einem Neustart.
HomeSpan 2.0 bekommt dazu die WLAN-Zugangsdaten des Türöffners (ohne sie startet es
den HomeKit-Dienst nicht), baut die Verbindung aber nicht selbst auf – das WLAN
verwaltet weiter der Türöffner. Serielle HomeSpan-Befehle sind abgeschaltet. Der Status in der
Weboberfläche zeigt, ob der Dienst wirklich läuft („wartet auf WLAN“, „bereit zum
Koppeln“, „gekoppelt“). Beim Start wartet HomeSpan einmalig 2 s (fest in der Bibliothek).

## Home Assistant

Voraussetzung: das Add-on **Mosquitto broker** und die **MQTT-Integration**.

1. In der Weboberfläche im Tab **Dienste** Broker (IP von Home Assistant),
   Port `1883` sowie Benutzer und Passwort eintragen → „Speichern & verbinden“.
2. Das Gerät **Türöffner** erscheint automatisch unter
   *Einstellungen → Geräte & Dienste → MQTT*.

| Entität | Typ | Funktion |
|---|---|---|
| Tür öffnen | Button | Summer auslösen (beendet laufenden Anruf) |
| Türsummer | Schloss | „Öffnen“/„Aufschließen“ löst den Summer aus |
| Letztes Ereignis | Sensor | z. B. „Geöffnet (Gästecode) – Paketdienst“ |
| SIP-Status | Sensor | „angemeldet“, „Zugangsdaten falsch“, … (Diagnose)|
| Anrufe annehmen | Schalter | Anrufe an den Türöffner ein/aus (Konfiguration)  |
| Klingel | Event | Ereignis `ring` bei jedem Klingeln (Türklingel)  |
| Es klingelt | Binärsensor | an, solange der Klingel-Hinweis aktiv ist (10 s) |
| Summer | Binärsensor | an, solange der Summer schaltet |
| Beim Klingeln anrufen | Schalter | Anruf beim Klingeln ein/aus (Konfiguration) |
| Nachtruhe | Schalter | Nachtruhe ein/aus (Konfiguration) |
| Praxis-Modus | Schalter | Praxis-Modus ein/aus (Konfiguration) |
| Tür / Tür zu lange offen | Binärsensor | nur wenn der Türkontakt aktiviert ist |
| Summer-Dauer | Zahl | 1–30 s (Konfiguration) |
| SIP registriert | Binärsensor | Verbindung zur Telefonanlage (Diagnose) |
| Klingeln / Öffnungen / Anrufe | Sensor | Zähler, bleiben über Neustarts erhalten |
| *Name* öffnen | Button | zweites Relais (nur wenn aktiviert) |

Jedes Ereignis wird zusätzlich auf `tueroeffner/<id>/event` veröffentlicht (JSON mit
`type`, `event`, `detail`) – praktisch für eigene Automationen.

Fällt der ESP aus, werden alle Entitäten als *nicht verfügbar* angezeigt.
Nach einem Neustart von Home Assistant meldet sich der ESP automatisch neu an. Ist der
Broker nicht erreichbar, versucht er es in wachsenden Abständen erneut (bis 5 min);
ein Broker-Name (auch `.local`) wird aufgelöst, ohne die Klingel zu blockieren.

Beispiel-Automation (Push mit Öffnen-Knopf):

```yaml
automation:
  - alias: Klingel Push
    trigger:
      - platform: state
        entity_id: event.turoffner_klingel
    action:
      - service: notify.mobile_app_dein_handy
        data:
          message: "Es klingelt an der Tür"
          data:
            actions:
              - action: TUER_AUF
                title: "Öffnen"

  - alias: Tür per Push öffnen
    trigger:
      - platform: event
        event_type: mobile_app_notification_action
        event_data:
          action: TUER_AUF
    action:
      - service: button.press
        target:
          entity_id: button.turoffner_tur_offnen
```

Die genauen Entity-IDs zeigt Home Assistant beim Gerät an.

## Anpassen

Grundeinstellungen in [src/config.h](src/config.h), u. a.:

| Einstellung | Standard | Bedeutung |
|---|---|---|
| `SIP_MAX_DIAL_SEC` | 15 | Anruf wird nach dieser Zeit beendet |
| `SIP_BEEP_SECONDS` | 6 | Dauer des Pieptons nach dem Abheben (0 = kein Ton) |
| `SIP_REG_EXPIRES` | 120 | Gültigkeit der SIP-Registrierung (s) |
| `RING_NOTIFY_MS` | 10000 | Anzeigedauer „Es klingelt!“ |
| `RING_COOLDOWN_MS` | 5000 | Sperre gegen Sturmklingeln |
| `SIP_PIN_CALL_SECONDS` | 30 | Gesprächsdauer mit Öffnen-Code |
| `WIFI_LOST_RESTART_MIN`  | 30 | Neustart, wenn das WLAN so lange weg ist |
| `WIFI_RETRY_SEC` | 60 | WLAN weg: so oft neu verbinden (s) |
| `ETH_NO_IP_RESTART_MIN`  | 10 | Ethernet: Neustart, wenn Link ohne IP so lange |
| `LOOP_WATCHDOG_SEC` | 60 | Watchdog, falls das Programm hängt |
| `HOSTNAME` | `tueroeffner` | Name im Netz (`http://tueroeffner.local`) |
| `TIME_ZONE` | MEZ/MESZ | Zeitzone für Verlauf und Nachtruhe |
| `SCREEN_TIMEOUT_SECONDS` | 60 | OLED-Bildschirmschoner (0 = aus) |
| `MQTT_DISCOVERY_PREFIX`  | `homeassistant` | Discovery-Prefix von Home Assistant |
| `WIFI_AP_PASSWORD` | `tuer-einrichten` | Standard-Passwort der WLAN-Einrichtung |
| `WIFI_PORTAL_SECONDS` | 300 | so lange bleibt die WLAN-Einrichtung offen |
| `WIFI_PORTAL_AFTER_MIN`  | 15 | WLAN-Einrichtung erst nach so langer WLAN-Störung  |
| `INCOMING_CALL_SECONDS`  | 30 | Dauer eines Anrufs an den Türöffner |
| `INCOMING_LOCK_FAILS` | 6 | falsche Codes bis zur Sperre (`INCOMING_LOCK_MIN`) |
| `AUTH_MAX_FAILS` | 5 | falsche Anmeldungen bis zur Sperre |
| `LOG_SIZE` | 30 | Einträge im (kurzen) Verlauf |
| `EVENT_FILE_MAX` | 48000 / 24000 | Größe einer Datei des langen Verlaufs (Bytes, 2 Dateien; ESP32 24000) |
| `FS_RESERVE_BYTES` | 24576 | im LittleFS immer frei für Einstellungen (Bytes) |
| `EVENT_FLUSH_MS` | 60000 | langen Verlauf höchstens so oft schreiben (ms) |
| `WEB_SEND_MAX_MS` | 5000 | Startseite/CSV höchstens so lange senden (ms) |
| `DOOR_PASS_WINDOW_SEC` | 10 | so lange nach dem Summer muss die Tür aufgehen |
| `USERS_MAX` | 8 | weitere Benutzer |
| `KEYPAD_LOCK_FAILS` | 5 | Fehlversuche am Tastenfeld bis zur Sperre (`KEYPAD_LOCK_MIN`) |
| `TELEGRAM_BUTTON_SEC` | 180 | Gültigkeit des Telegram-Knopfs „Öffnen“ |

**Fehlersuche SIP:** Nach jedem Gespräch steht eine Zeile im Log (seriell/Syslog), z. B.
`SIP: Gespraech beendet (PCMA, DTMF-PT 101, Gegenstelle 192.168.20.247, RTP 312, Tasten 1)`.
`RTP 0` heißt: kein Audio vom Telefon angekommen; `Tasten 0` trotz Tastendruck: die Anlage
schickt DTMF nicht per RFC 4733/SIP INFO (z. B. nur als Ton im Audio – in der Anlage
umstellen); `verworfen … von <IP>`: RTP kam von einer unerwarteten Adresse.
Für alle SIP-Pakete in [platformio.ini](platformio.ini) `build_flags = -DDEBUGLOG`
einkommentieren – dann werden sie seriell ausgegeben.

## Projektstruktur

| Datei | Inhalt |
|---|---|
| [src/main.cpp](src/main.cpp) | Start, Loop, WLAN/Einrichtung, Netzdienste, Watchdog, Selbstheilung |
| [src/settings.cpp](src/settings.cpp) | Einstellungen (eine Tabelle für Datei, Sicherung, Wiederherstellung), Zähler/Verlauf, Übernahme aus dem EEPROM |
| [src/events.cpp](src/events.cpp) | Ereignisprotokoll, serielle Ausgabe, Syslog |
| [src/door.cpp](src/door.cpp) | Relais/Summer, Eingänge, Zeitfenster, Display, Status-LED |
| [src/phone.cpp](src/phone.cpp) | SIP-Anmeldung, Rufkette, Codes, Anrufe an den Türöffner |
| [src/push.cpp](src/push.cpp) | ntfy / Telegram, Telegram-Bot |
| [src/keypad.cpp](src/keypad.cpp) | Tastenfeld / RFID (Wiegand) |
| [src/homekit.cpp](src/homekit.cpp) | Apple Home (HomeSpan) |
| [src/net.cpp](src/net.cpp) | Netzwerk-Abstraktion WLAN / Ethernet |
| [src/holidays.h](src/holidays.h) | gesetzliche Feiertage je Bundesland |
| [src/timewin.h](src/timewin.h) | Zeitfenster (auch über Mitternacht) |
| [src/presswatch.h](src/presswatch.h) | verpasste Tastendrücke per Interrupt nachholen |
| [src/mqtt.cpp](src/mqtt.cpp) | Home Assistant |
| [src/web.cpp](src/web.cpp) | HTTP-API, Anmeldung, Schutzmechanismen |
| [src/web/index.html](src/web/index.html) | Weboberfläche |
| [src/config.h](src/config.h) | Pins und Grundeinstellungen |
| [lib/ArduinoSIP](lib/ArduinoSIP) | SIP-Client (REGISTER, INVITE, Digest, RTP, eingehende Anrufe) |

Neue Einstellung: Variable in `settings.cpp` anlegen, eine Zeile in der Tabelle
`SETTINGS` ergänzen – Speichern, Sicherung und Wiederherstellung funktionieren damit
automatisch.

## Tests und CI

- **Host-Tests** ([tests/host](tests/host)): SIP-Bibliothek (Digest nach RFC 2617,
  REGISTER, ausgehende/eingehende Anrufe, Klingel-Anrufe, DTMF, Wiederholungen bei
  Paketverlust, Kurzformen/Schreibweisen, Re-INVITE, 20 000 Zufallspakete)
  sowie Feiertagsberechnung, Zeitfenster über Mitternacht und das Nachholen verpasster
  Tastendrücke – übersetzt mit AddressSanitizer/UBSan:

  ```bash
  bash tests/host/run.sh      # Linux oder WSL, braucht g++
  ```

- Beim Bauen prüft [tools/embed_html.py](tools/embed_html.py) das JavaScript der
  Weboberfläche mit Node (falls installiert) und bricht bei Syntaxfehlern ab.
- **GitHub Actions** ([.github/workflows/ci.yml](.github/workflows/ci.yml)) baut bei
  jedem Push alle Varianten, führt die Host-Tests aus und stellt die `firmware.bin`
  als Artefakt bereit.

## Lizenz

Dieses Projekt steht unter der [Apache License 2.0](LICENSE).
Die mitgelieferte Bibliothek [lib/ArduinoSIP](lib/ArduinoSIP) stammt von
Juergen Liegner und Thorsten Godau, wurde für dieses Projekt erweitert und steht
weiterhin unter der BSD-3-Clause-Lizenz (siehe [NOTICE](NOTICE) und den Kopf von
`ArduinoSIP.h`).

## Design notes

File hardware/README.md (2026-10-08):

# Steuerplatine (KiCad)

KiCad-10-Projekt für eine eigene Platine mit ESP32-WROOM-32E. Die Pinbelegung entspricht dem ESP32-Zweig in [src/config.h](../src/config.h), es ist also keine Firmware-Änderung nötig.

| Datei | Inhalt |
| --- | --- |
| `esp_dooropen.kicad_pro` / `.kicad_sch` | KiCad-Projekt und Schaltplan |
| `schaltplan.pdf` | Schaltplan als PDF |
| `stueckliste.csv` | Stückliste, gruppiert nach Wert und Footprint |

Stand: nur der Schaltplan. Ein PCB-Layout gibt es noch nicht.

## Funktionsblöcke

- **Versorgung:** 12 V DC über Hohlstecker 5,5/2,1 oder Schraubklemme. Danach PTC 1,1 A, Verpolschutz SS34 und TVS-Diode SMBJ15CA. Ein RECOM R-78E5.0-1.0 erzeugt 5 V, ein AMS1117 daraus 3,3 V. USB-5V ist über eine Schottky-Diode entkoppelt, sodass USB und 12 V gleichzeitig angeschlossen sein dürfen.
- **USB-C:** CH340C mit Auto-Reset über DTR/RTS. Geflasht wird direkt per PlatformIO, ohne Tasten zu drücken. RESET und BOOT gibt es trotzdem als Taster.
- **Relais 1 und 2:** SRD-12VDC-SL-C mit 12-V-Spule, angesteuert über AO3400A mit Freilaufdiode und LED. Die Kontakte NO/COM/NC sind potentialfrei auf Schraubklemmen geführt.
- **Klingelsignal:** Zwei Varianten, beide verdrahtet. Sie wirken als ODER auf GPIO27 und brauchen keine Jumper.
  - Potentialfreier Kontakt an J4, Klemme 1 gegen GND.
  - 8–24 V AC oder DC an J5 über den Optokoppler LTV-814 (PC814). Der Optokoppler hat antiparallele LEDs, die Polarität ist also egal, und er trennt galvanisch. C11 überbrückt die Nulldurchgänge bei Wechselspannung.
- **Taster und Türkontakt:** Je 1 kΩ in Serie, 10 kΩ Pull-up und 100 nF gegen Störungen auf langen Leitungen.
- **Wiegand:** 12-V-Versorgung über PTC 200 mA. D0/D1 laufen über Schottky-Dioden BAT54W, daher sind 5-V-Leser ohne Pegelwandler erlaubt.
- **Erweiterungen:** OLED-Steckplatz (I2C, 3,3 V) und eine Erweiterungsleiste mit IO4, IO14, IO16 und IO17.

## Klemmenbelegung

| Klemme | Pins |
| --- | --- |
| J2 12 V | 1 +12 V, 2 GND |
| J4 Eingänge | 1 Klingel potentialfrei, 2 GND, 3 Klingeltaster, 4 Summertaster, 5 Türkontakt, 6 GND |
| J5 Klingel AC/DC | 1, 2 (8–24 V, beliebige Polarität) |
| J6 Wiegand | 1 +12 V, 2 GND, 3 D0, 4 D1 |
| J9 / J10 Relais | 1 NO, 2 COM, 3 NC |

## Zuordnung der GPIOs

| GPIO | Funktion |
| --- | --- |
| 26 | Relais 1 (Türsummer) |
| 13 | Relais 2 |
| 27 | Klingelsignal |
| 32 | Klingeltaster |
| 33 | Summertaster |
| 25 | Türkontakt |
| 18 / 19 | Wiegand D0 / D1 |
| 21 / 22 | I2C SDA / SCL |
| 2 | Status-LED |

## Hinweise

- **ERC:** Die einzige Meldung lautet „Power output an Power output“ zwischen CH340C-V3 und AMS1117. Das ist gewollt: Laut Datenblatt wird V3 bei 3,3-V-Betrieb mit VCC verbunden.
- **Nur Kleinspannung:** Die Platine ist für Kleinspannung ausgelegt (Klingeltrafo, Türöffner 8–24 V). Für 230 V an den Relaiskontakten fehlen die nötigen Luft- und Kriechstrecken.
- **Antenne:** Beim Layout muss die Antenne des WROOM-Moduls über den Platinenrand ragen. Darunter dürfen weder Kupfer noch Bauteile liegen.
- **Strapping-Pins:** GPIO12, GPIO15 und GPIO5 sind bewusst frei. GPIO0 und EN werden nur vom Auto-Reset und den Tastern benutzt.
- **Relais beim Start:** Die Relais hängen an GPIO26 und GPIO13 (keine Strapping-Pins, kein Pull-up beim Reset). R23 bzw. R25 (100 kΩ) halten die Gates von Q3/Q4 auf GND, solange der ESP32 startet – die Relais ziehen dabei nicht an. Bei Änderungen die Relais nicht auf GPIO5 oder GPIO15 legen (interner Pull-up beim Reset, siehe [README](../README.md#relais-beim-start)); diese Pull-downs nicht weglassen.

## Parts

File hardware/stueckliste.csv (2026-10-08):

Referenz | Wert | Footprint | Anzahl
C1 | 47µF/35V | Capacitor_SMD:CP_Elec_6.3x7.7 | 1
C2 | 10µF/25V | Capacitor_SMD:C_1206_3216Metric | 1
C3,C5 | 22µF/10V | Capacitor_SMD:C_1206_3216Metric | 2
C4,C8 | 10µF | Capacitor_SMD:C_0805_2012Metric | 2
C6,C7,C9,C12,C13,C14 | 100nF | Capacitor_SMD:C_0805_2012Metric | 6
C10 | 1µF | Capacitor_SMD:C_0805_2012Metric | 1
C11 | 4.7µF | Capacitor_SMD:C_0805_2012Metric | 1
D1 | SS34 | Diode_SMD:D_SMA | 1
D2 | SMBJ15CA | Diode_SMD:D_SMB | 1
D3,D4 | B5819W | Diode_SMD:D_SOD-123 | 2
D5 | grün PWR | LED_SMD:LED_0805_2012Metric | 1
D6 | gelb STATUS | LED_SMD:LED_0805_2012Metric | 1
D7,D8 | BAT54W | Package_TO_SOT_SMD:SOT-323_SC-70 | 2
D9,D10 | 1N4148W | Diode_SMD:D_SOD-123 | 2
D11 | rot REL1 | LED_SMD:LED_0805_2012Metric | 1
D12 | rot REL2 | LED_SMD:LED_0805_2012Metric | 1
F1 | 1.1A PTC (MF-MSMF110) | Fuse:Fuse_1812_4532Metric | 1
F2 | 200mA PTC (MF-MSMF020) | Fuse:Fuse_1206_3216Metric | 1
H1,H2,H3,H4 | M3 | MountingHole:MountingHole_3.2mm_M3 | 4
J1 | 12V DC 5.5/2.1 | Connector_BarrelJack:BarrelJack_Horizontal | 1
J2 | 12V DC IN | TerminalBlock_Phoenix:TerminalBlock_Phoenix_MKDS-1,5-2-5.08_1x02_P5.08mm_Horizontal | 1
J3 | USB-C (HRO TYPE-C-31-M-12) | Connector_USB:USB_C_Receptacle_HRO_TYPE-C-31-M-12 | 1
J4 | Eingänge | TerminalBlock_Phoenix:TerminalBlock_Phoenix_MKDS-1,5-6-5.08_1x06_P5.08mm_Horizontal | 1
J5 | Klingel 8-24V AC/DC | TerminalBlock_Phoenix:TerminalBlock_Phoenix_MKDS-1,5-2-5.08_1x02_P5.08mm_Horizontal | 1
J6 | Wiegand | TerminalBlock_Phoenix:TerminalBlock_Phoenix_MKDS-1,5-4-5.08_1x04_P5.08mm_Horizontal | 1
J7 | OLED I2C | Connector_PinHeader_2.54mm:PinHeader_1x04_P2.54mm_Vertical | 1
J8 | Erweiterung | Connector_PinHeader_2.54mm:PinHeader_1x06_P2.54mm_Vertical | 1
J9 | Relais 1 NO/COM/NC | TerminalBlock_Phoenix:TerminalBlock_Phoenix_MKDS-1,5-3-5.08_1x03_P5.08mm_Horizontal | 1
J10 | Relais 2 NO/COM/NC | TerminalBlock_Phoenix:TerminalBlock_Phoenix_MKDS-1,5-3-5.08_1x03_P5.08mm_Horizontal | 1
K1,K2 | SRD-12VDC-SL-C | Relay_THT:Relay_SPDT_SANYOU_SRD_Series_Form_C | 2
Q1,Q2 | MMBT3904 | Package_TO_SOT_SMD:SOT-23 | 2
Q3,Q4 | AO3400A | Package_TO_SOT_SMD:SOT-23 | 2
R1,R9,R10,R11,R12 | 1k | Resistor_SMD:R_0805_2012Metric | 5
R2,R3 | 5.1k | Resistor_SMD:R_0805_2012Metric | 2
R4,R5,R6,R7,R13,R14,R15,R16 | 10k | Resistor_SMD:R_0805_2012Metric | 8
R8 | 330 | Resistor_SMD:R_0805_2012Metric | 1
R17 | 2.2k 1W | Resistor_THT:R_Axial_DIN0414_L11.9mm_D4.5mm_P15.24mm_Horizontal | 1
R18,R19,R20,R21,R26,R27 | 4.7k | Resistor_SMD:R_0805_2012Metric | 6
R22,R24 | 100 | Resistor_SMD:R_0805_2012Metric | 2
R23,R25 | 100k | Resistor_SMD:R_0805_2012Metric | 2
SW1 | RESET | Button_Switch_SMD:SW_SPST_TL3342 | 1
SW2 | BOOT | Button_Switch_SMD:SW_SPST_TL3342 | 1
U1 | R-78E5.0-1.0 | Converter_DCDC:Converter_DCDC_RECOM_R-78E-0.5_THT | 1
U2 | AMS1117-3.3 | Package_TO_SOT_SMD:SOT-223-3_TabPin2 | 1
U3 | USBLC6-2SC6 | Package_TO_SOT_SMD:SOT-23-6 | 1
U4 | CH340C | Package_SO:SOIC-16_3.9x9.9mm_P1.27mm | 1
U5 | ESP32-WROOM-32E-N4 | RF_Module:ESP32-WROOM-32E | 1
U6 | LTV-814 (PC814) | Package_DIP:DIP-4_W7.62mm | 1

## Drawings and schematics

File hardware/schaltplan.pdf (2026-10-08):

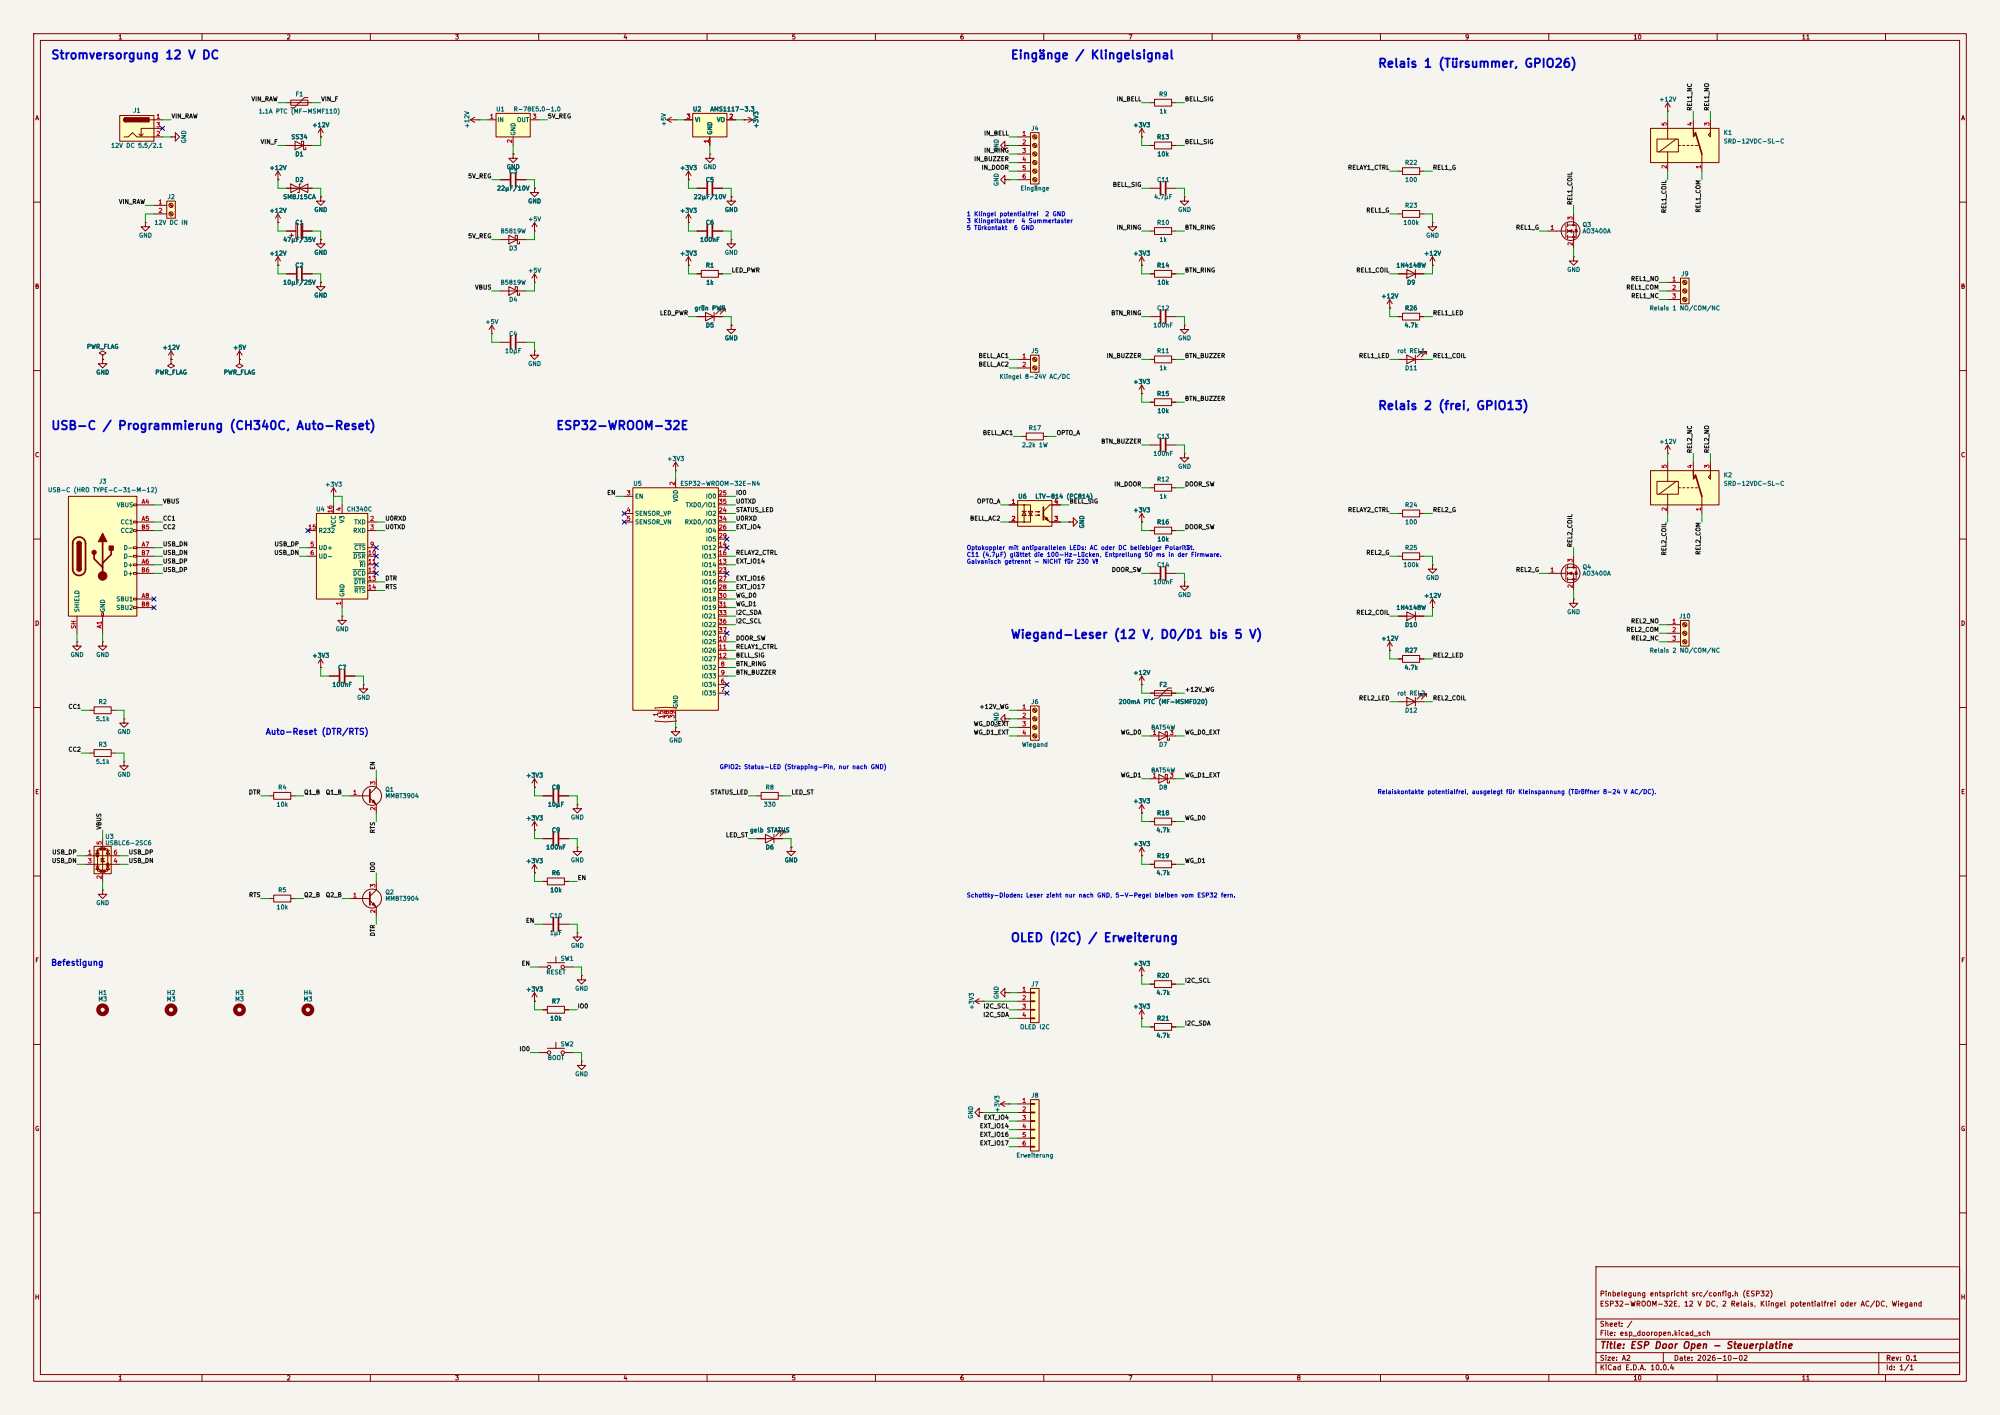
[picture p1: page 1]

3 Klingeltaster 4 Summertaster 5 Türkontakt 6 GND Stromversorgung 12 V DC

J9 Relais 1 NO/COM/NC

USB-C / Programmierung (CH340C, Auto-Reset)

4 UD+ 5 UD- 6 CTS 9 DSR 10 RI 11 DCD 12 DTR 13 RTS 14 R232 15 VCC U4 16CH340C
REL2_G Q1_B

Auto-Reset (DTR/RTS)

GPIO2: Status-LED (Strapping-Pin, nur nach GND)

Schottky-Dioden: Leser zieht nur nach GND, 5-V-Pegel bleiben vom ESP32 fern. OLED (I2C) / Erweiterung

Pinbelegung entspricht src/config.h (ESP32)
ESP32-WROOM-32E, 12 V DC, 2 Relais, Klingel potentialfrei oder AC/DC, Wiegand

Sheet: /
File: esp_dooropen.kicad_sch
Title: ESP Door Open - Steuerplatine

Size: A2 | Rev: 0.1
KiCad E.D.A. 10.0.4 | Id: 1/1

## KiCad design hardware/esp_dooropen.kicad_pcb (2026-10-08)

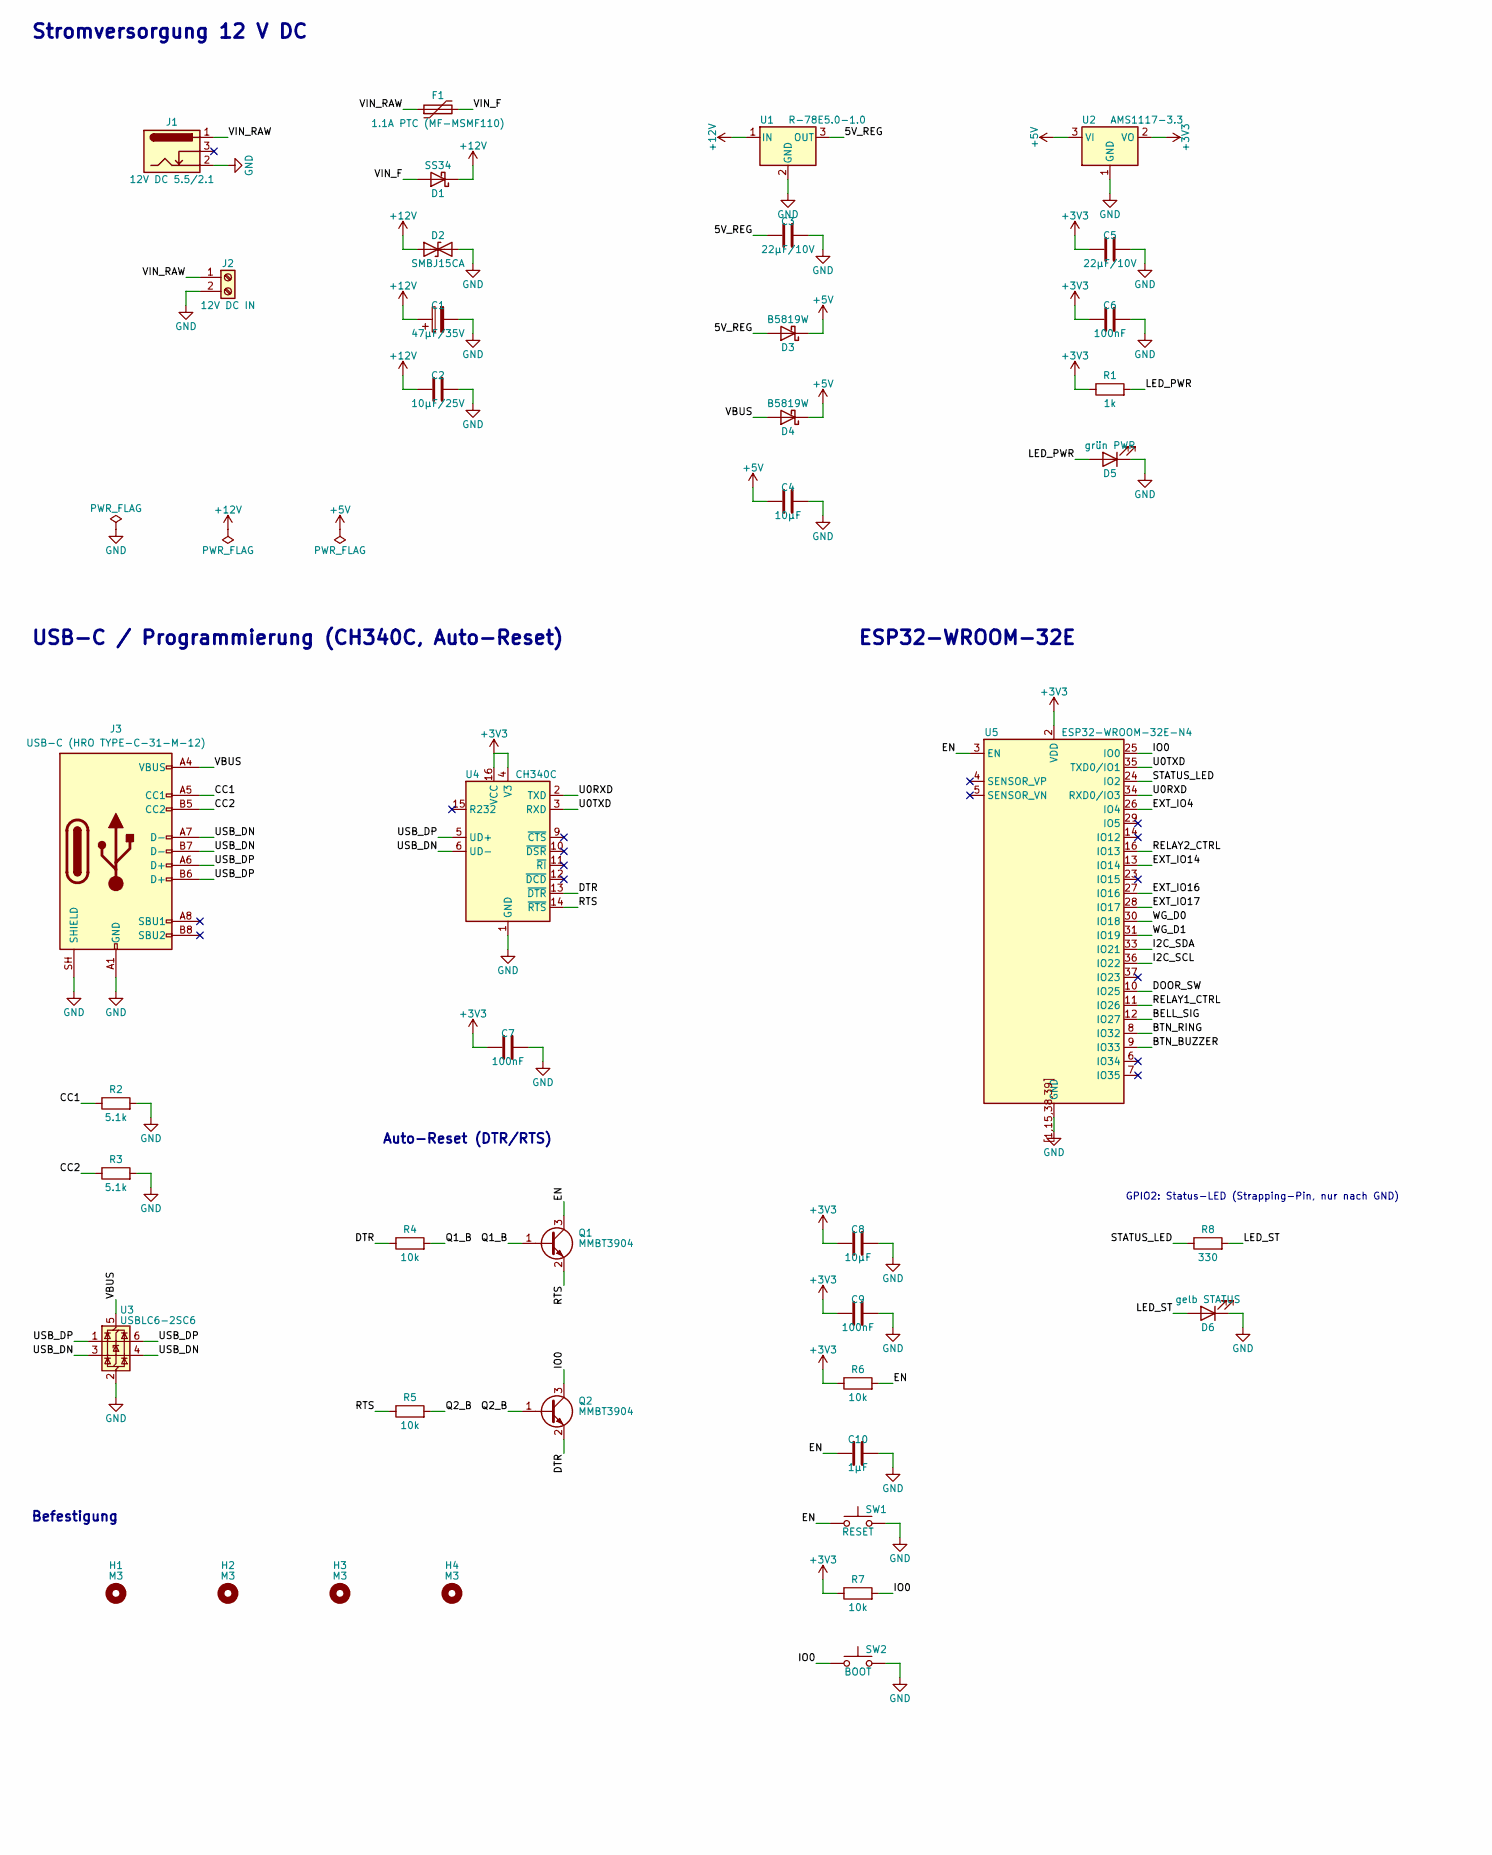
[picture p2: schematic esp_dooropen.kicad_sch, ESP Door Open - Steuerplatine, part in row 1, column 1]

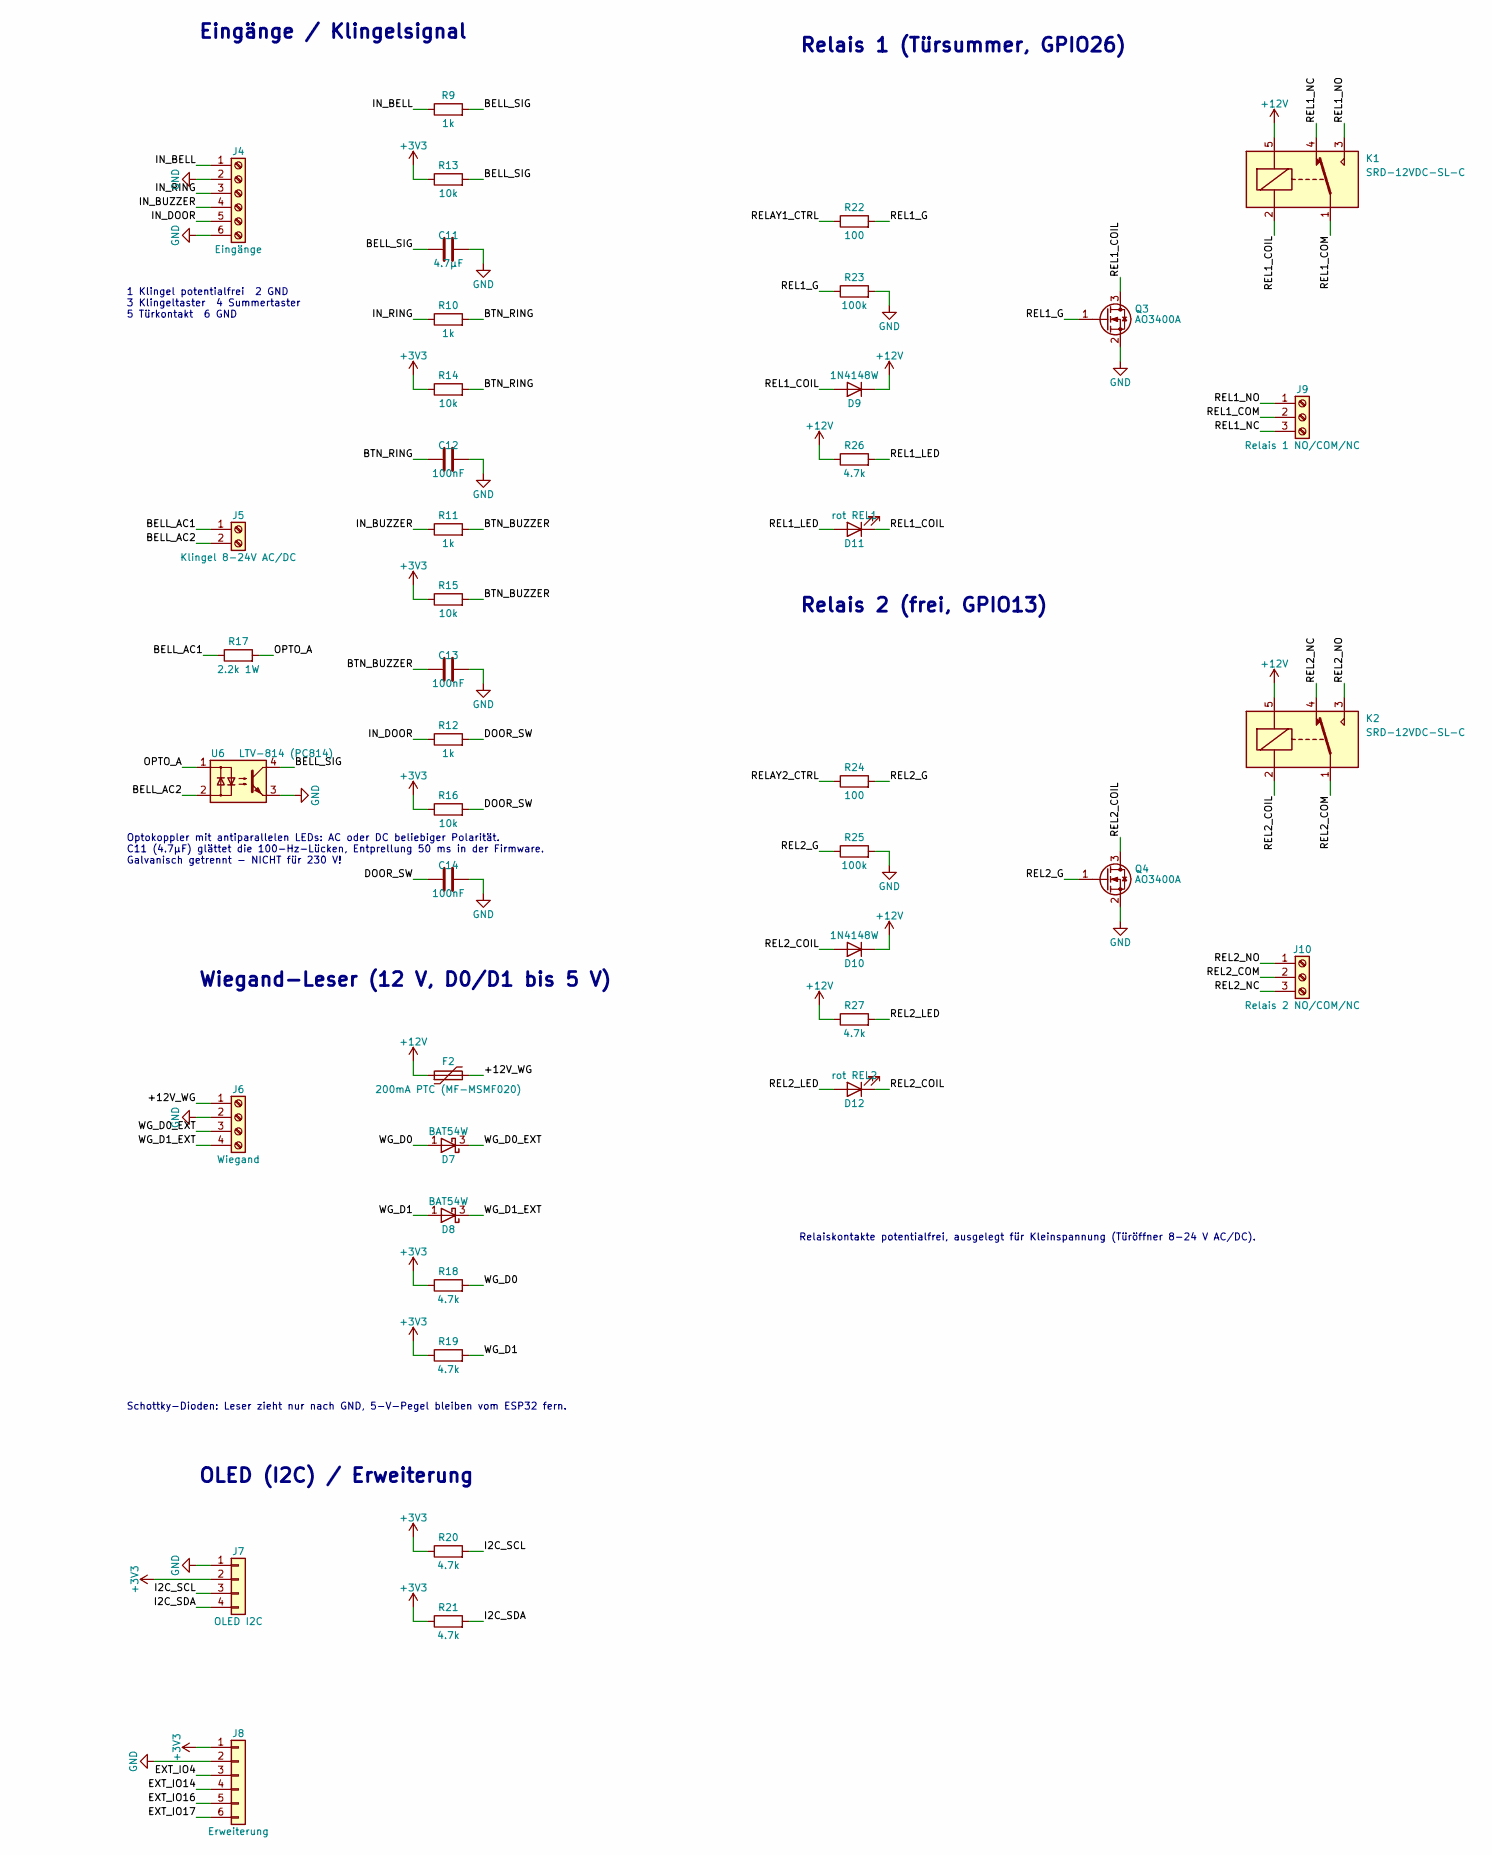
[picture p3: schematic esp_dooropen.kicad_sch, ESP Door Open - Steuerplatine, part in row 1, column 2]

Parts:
C1: 47µF/35V; CP_Elec_6.3x7.7
C2: 10µF/25V; C_1206_3216Metric
C3, C5: 22µF/10V; C_1206_3216Metric
C4, C8: 10µF; C_0805_2012Metric
C6, C7, C9, C12, C13, C14: 100nF; C_0805_2012Metric
C10: 1µF; C_0805_2012Metric
C11: 4.7µF; C_0805_2012Metric
D1: SS34; D_SMA
D2: SMBJ15CA; D_SMB
D3, D4: B5819W; D_SOD-123
D5: grün PWR; LED_0805_2012Metric
D6: gelb STATUS; LED_0805_2012Metric
D7, D8: BAT54W; SOT-323_SC-70
D9, D10: 1N4148W; D_SOD-123
D11: rot REL1; LED_0805_2012Metric
D12: rot REL2; LED_0805_2012Metric
F1: 1.1A PTC (MF-MSMF110); Fuse_1812_4532Metric
F2: 200mA PTC (MF-MSMF020); Fuse_1206_3216Metric
H1, H2, H3, H4: M3; MountingHole_3.2mm_M3
J1: 12V DC 5.5/2.1; BarrelJack_Horizontal
J2: 12V DC IN; TerminalBlock_Phoenix_MKDS-1,5-2-5.08_1x02_P5.08mm_Horizont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
J3: USB-C (HRO TYPE-C-31-M-12); USB_C_Receptacle_HRO_TYPE-C-31-M-12
J4: Eingänge; TerminalBlock_Phoenix_MKDS-1,5-6-5.08_1x06_P5.08mm_Horizont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
J5: Klingel 8-24V AC/DC; TerminalBlock_Phoenix_MKDS-1,5-2-5.08_1x02_P5.08mm_Horizont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
J6: Wiegand; TerminalBlock_Phoenix_MKDS-1,5-4-5.08_1x04_P5.08mm_Horizont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
J7: OLED I2C; PinHeader_1x04_P2.54mm_Vertical
J8: Erweiterung; PinHeader_1x06_P2.54mm_Vertical
J9: Relais 1 NO/COM/NC; TerminalBlock_Phoenix_MKDS-1,5-3-5.08_1x03_P5.08mm_Horizont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
J10: Relais 2 NO/COM/NC; TerminalBlock_Phoenix_MKDS-1,5-3-5.08_1x03_P5.08mm_Horizont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
K1, K2: SRD-12VDC-SL-C; Relay_SPDT_SANYOU_SRD_Series_Form_C
Q1, Q2: MMBT3904; SOT-23
Q3, Q4: AO3400A; SOT-23
R1, R9, R10, R11, R12: 1k; R_0805_2012Metric
R2, R3: 5.1k; R_0805_2012Metric
R4, R5, R6, R7, R13, R14, R15, R16: 10k; R_0805_2012Metric
R8: 330; R_0805_2012Metric
R17: 2.2k 1W; R_Axial_DIN0414_L11.9mm_D4.5mm_P15.24mm_Horizontal
R18, R19, R20, R21, R26, R27: 4.7k; R_0805_2012Metric
R22, R24: 100; R_0805_2012Metric
R23, R25: 100k; R_0805_2012Metric
SW1: RESET; SW_SPST_TL3342
SW2: BOOT; SW_SPST_TL3342
U1: R-78E5.0-1.0; Converter_DCDC_RECOM_R-78E-0.5_THT
U2: AMS1117-3.3; SOT-223-3_TabPin2
U3: USBLC6-2SC6; SOT-23-6
U4: CH340C; SOIC-16_3.9x9.9mm_P1.27mm
U5: ESP32-WROOM-32E-N4; ESP32-WROOM-32E
U6: LTV-814 (PC814); DIP-4_W7.62mm

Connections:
+3V3: C5.1, C6.1, C7.1, C8.1, C9.1, J7.2, J8.1, R1.1, R6.1, R7.1, R13.1, R14.1, R15.1, R16.1, R18.1, R19.1, R20.1, R21.1, U2.2 (VO), U4.4 (V3), U4.16 (VCC), U5.2 (VDD)
+5V: C4.1, D3.1 (K), D4.1 (K), U2.3 (VI)
+12V: C1.1, C2.1, D1.1 (K), D2.1 (A1), D9.1 (K), D10.1 (K), F2.1, K1.5, K2.5, R26.1, R27.1, U1.1 (IN)
/5V_REG: C3.1, D3.2 (A), U1.3 (OUT)
/+12V_WG: F2.2, J6.1
/BELL_AC1: J5.1, R17.1
/BELL_AC2: J5.2, U6.2
/BELL_SIG: C11.1, R9.2, R13.2, U5.12 (IO27), U6.4
/BTN_BUZZER: C13.1, R11.2, R15.2, U5.9 (IO33)
/BTN_RING: C12.1, R10.2, R14.2, U5.8 (IO32)
/CC1: J3.A5 (CC1), R2.1
/CC2: J3.B5 (CC2), R3.1
/DOOR_SW: C14.1, R12.2, R16.2, U5.10 (IO25)
/DTR: Q2.2 (E), R4.1, U4.13 (~DTR)
/EN: C10.1, Q1.3 (C), R6.2, SW1.1, U5.3 (EN)
/EXT_IO4: J8.3, U5.26 (IO4)
/EXT_IO14: J8.4, U5.13 (IO14)
/EXT_IO16: J8.5, U5.27 (IO16)
/EXT_IO17: J8.6, U5.28 (IO17)
/I2C_SCL: J7.3, R20.2, U5.36 (IO22)
/I2C_SDA: J7.4, R21.2, U5.33 (IO21)
/IN_BELL: J4.1, R9.1
/IN_BUZZER: J4.4, R11.1
/IN_DOOR: J4.5, R12.1
/IN_RING: J4.3, R10.1
/IO0: Q2.3 (C), R7.2, SW2.1, U5.25 (IO0)
/LED_PWR: D5.2 (A), R1.2
/LED_ST: D6.2 (A), R8.2
/OPTO_A: R17.2, U6.1
/Q1_B: Q1.1 (B), R4.2
/Q2_B: Q2.1 (B), R5.2
/REL1_COIL: D9.2 (A), D11.1 (K), K1.2, Q3.3 (D)
/REL1_COM: J9.2, K1.1
/REL1_G: Q3.1 (G), R22.2, R23.1
/REL1_LED: D11.2 (A), R26.2
/REL1_NC: J9.3, K1.4
/REL1_NO: J9.1, K1.3
/REL2_COIL: D10.2 (A), D12.1 (K), K2.2, Q4.3 (D)
/REL2_COM: J10.2, K2.1
/REL2_G: Q4.1 (G), R24.2, R25.1
/REL2_LED: D12.2 (A), R27.2
/REL2_NC: J10.3, K2.4
/REL2_NO: J10.1, K2.3
/RELAY1_CTRL: R22.1, U5.11 (IO26)
/RELAY2_CTRL: R24.1, U5.16 (IO13)
/RTS: Q1.2 (E), R5.1, U4.14 (~RTS)
/STATUS_LED: R8.1, U5.24 (IO2)
/U0RXD: U4.2 (TXD), U5.34 (RXD0/IO3)
/U0TXD: U4.3 (RXD), U5.35 (TXD0/IO1)
/USB_DN: J3.A7 (D-), J3.B7 (D-), U3.3 (I/O2), U3.4 (I/O2), U4.6 (UD-)
/USB_DP: J3.A6 (D+), J3.B6 (D+), U3.1 (I/O1), U3.6 (I/O1), U4.5 (UD+)
/VBUS: D4.2 (A), J3.A4 (VBUS), J3.A9 (VBUS), J3.B4 (VBUS), J3.B9 (VBUS), U3.5 (VBUS)
/VIN_F: D1.2 (A), F1.2
/VIN_RAW: F1.1, J1.1, J2.1
/WG_D0: D7.1 (A), R18.2, U5.30 (IO18)
/WG_D0_EXT: D7.3 (K), J6.3
/WG_D1: D8.1 (A), R19.2, U5.31 (IO19)
/WG_D1_EXT: D8.3 (K), J6.4
GND: C1.2, C2.2, C3.2, C4.2, C5.2, C6.2, C7.2, C8.2, C9.2, C10.2, C11.2, C12.2, C13.2, C14.2, D2.2 (A2), D5.1 (K), D6.1 (K), J1.2, J2.2, J3.A1 (GND), J3.A12 (GND), J3.B1 (GND), J3.B12 (GND), J3.SH (SHIELD), J4.2, J4.6, J6.2, J7.1, J8.2, Q3.2 (S), Q4.2 (S), R2.2, R3.2, R23.2, R25.2, SW1.2, SW2.2, U1.2 (GND), U2.1 (GND), U3.2 (GND), U4.1 (GND), U5.1 (GND), U5.15 (GND), U5.38 (GND), U5.39 (GND), U5.[1,15,38,39] (GND), U6.3

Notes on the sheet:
Wiegand-Leser (12 V, D0/D1 bis 5 V)
Relais 2 (frei, GPIO13)
1 Klingel potentialfrei 2 GND 3 Klingeltaster 4 Summertaster 5 Türkontakt 6 GND
Optokoppler mit antiparallelen LEDs: AC oder DC beliebiger Polarität. C11 (4.7µF) glättet die 100-Hz-Lücken, Entprellung 50 ms in der Firmware. Galvanisch getrennt - NICHT für 230 V!
OLED (I2C) / Erweiterung
GPIO2: Status-LED (Strapping-Pin, nur nach GND)
Auto-Reset (DTR/RTS)
Stromversorgung 12 V DC
Befestigung
USB-C / Programmierung (CH340C, Auto-Reset)
Schottky-Dioden: Leser zieht nur nach GND, 5-V-Pegel bleiben vom ESP32 fern.
Relaiskontakte potentialfrei, ausgelegt für Kleinspannung (Türöffner 8-24 V AC/DC).
Eingänge / Klingelsignal
ESP32-WROOM-32E
Relais 1 (Türsummer, GPIO26)

Board: 2 copper layers, 83 parts (0 on the bottom side), 59 nets, no tracks yet.

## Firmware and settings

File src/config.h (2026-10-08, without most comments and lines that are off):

#pragma once
#if defined(ETH_BOARD_WT32)
#define USE_ETHERNET
#define ETH_PHY_ADDR_CFG   1
#define ETH_PHY_POWER_PIN  16
#define ETH_PHY_MDC_PIN    23
#define ETH_PHY_MDIO_PIN   18
#define ETH_CLK_MODE_CFG   ETH_CLOCK_GPIO0_IN
#define PIN_SDA        15   // I2C (nur falls ein OLED angeschlossen wird)
#define PIN_SCL        14
#define PIN_RELAY      4    // Relais Tuersummer (active-high)
#define RELAY_ACTIVE_LOW  false
#define PIN_SIGNAL     32   // Klingel-Kontakt gegen GND
#define SIGNAL_ACTIVE_LOW true
#define PIN_BTN_RING   33   // Klingel-Taster gegen GND
#define PIN_BTN_BUZZER 12   // Summer-Taster gegen GND (Strapping-Pin: nie extern auf 3,3 V ziehen)
#define PIN_DOOR       2    // Tuerkontakt gegen GND
#define PIN_STATUS_LED    17
#define STATUS_LED_ACTIVE_LOW false
#define PIN_RELAY2     5    // RXD-Pin des Moduls (UART2), frei nutzbar
#define RELAY2_ACTIVE_LOW false
#define PIN_WG_D0      35   // Wiegand D0 (Pull-up/Pegelwandler noetig, siehe README)
#define PIN_WG_D1      36   // Wiegand D1
#elif defined(ESP32)
#define PIN_SDA        21   // GPIO21 (I2C SDA)
#define PIN_SCL        22   // GPIO22 (I2C SCL)
#define PIN_RELAY      26   // GPIO26
#define RELAY_ACTIVE_LOW  false
#define PIN_SIGNAL     27   // GPIO27
#define SIGNAL_ACTIVE_LOW true
#define PIN_BTN_RING   32   // GPIO32: Klingel-Taster (wirkt wie das Klingelsignal)
#define PIN_BTN_BUZZER 33   // GPIO33: Summer-Taster (oeffnet die Tuer)
#define PIN_DOOR       25   // GPIO25
#define PIN_STATUS_LED    2       // GPIO2 (Onboard-LED, active-high)
#define STATUS_LED_ACTIVE_LOW false
#define PIN_RELAY2     13   // GPIO13
#define RELAY2_ACTIVE_LOW false
#define PIN_WG_D0      18   // GPIO18
#define PIN_WG_D1      19   // GPIO19
#else
#define PIN_SDA        D5   // GPIO14  (Onboard-OLED)
#define PIN_SCL        D6   // GPIO12  (Onboard-OLED)
#define PIN_RELAY      D1   // GPIO5
#define RELAY_ACTIVE_LOW  false
#define PIN_SIGNAL     D2   // GPIO4
#define SIGNAL_ACTIVE_LOW true
#define PIN_BTN_RING   D7   // GPIO13: Klingel-Taster (wirkt wie das Klingelsignal)
#define PIN_BTN_BUZZER D3   // GPIO0:  Summer-Taster (oeffnet die Tuer)
#define PIN_DOOR       3    // GPIO3 (RX)
#define DOOR_ON_RX_PIN
#define PIN_STATUS_LED    LED_BUILTIN
#define STATUS_LED_ACTIVE_LOW true
#define PIN_RELAY2     D0   // GPIO16
#define RELAY2_ACTIVE_LOW false
#endif
#define OLED_WIDTH     128
#define OLED_HEIGHT    64
#define DEFAULT_BUZZER_SECONDS   3
#define MIN_BUZZER_SECONDS       1
#define MAX_BUZZER_SECONDS       30
#define SIGNAL_DEBOUNCE_MS       50
#define SIGNAL_AC_HOLD_MS        40
#define SIGNAL_MIN_SAMPLES       3
#define RING_BUZZER_GUARD_MS     300
#define SIGNAL_HOLD_MS           3000
#define RING_NOTIFY_MS           10000
#define RING_COOLDOWN_MS         5000
#define WIFI_AP_NAME             "Tueroeffner-Setup"
#define WIFI_AP_PASSWORD         "tuer-einrichten"
#define WIFI_PORTAL_SECONDS      300
#define WIFI_PORTAL_AFTER_MIN    15
#define WIFI_RETRY_SEC           60
#define HOSTNAME                 "tueroeffner"
#define NTP_SERVER   "pool.ntp.org"
#define NTP_SERVER2  "de.pool.ntp.org"
#define TIME_ZONE    "CET-1CEST,M3.5.0,M10.5.0/3"   // Mitteleuropa mit Sommerzeit
#define COUNTER_SAVE_MS  300000UL
#define LOG_SIZE         30
#define PW_RESET_HOLD_MS 5000
#define PW_RESET_RELEASE_MS 10000
#define WIFI_LOST_RESTART_MIN   30
#define ETH_NO_IP_RESTART_MIN   10
#define MIN_FREE_HEAP           8000
#define MIN_FREE_BLOCK          3000
#define LOOP_WATCHDOG_SEC       60
#define AUTH_MAX_FAILS          5
#define AUTH_LOCK_SEC           60
#define WEB_SEND_MAX_MS         5000
#define PUSH_TIMEOUT_MS         5000
#define PUSH_DNS_TIMEOUT_MS     2000
#define PUSH_TLS_MIN_BLOCK      17000
#define PUSH_TLS_MIN_HEAP       27000
#define PUSH_QUEUE_LEN          3
#define SIP_PIN_CALL_SECONDS    30
#define SYSLOG_PORT             514
#define INCOMING_CALL_SECONDS   30     // so lange bleibt der Anruf offen
#define INCOMING_MAX_TRIES      3      // falsche Codes je Anruf, dann auflegen
#define INCOMING_LOCK_FAILS     6      // falsche Codes insgesamt ...
#define INCOMING_LOCK_MIN       15     // ... innerhalb/fuer so viele Minuten -> Sperre
#define GUEST_CODES_MAX         5      // Anzahl Gaestecodes
#define DOOR_PASS_WINDOW_SEC    10
#if defined(ESP32)
#define EVENT_FILE_MAX          24000
#else
#define EVENT_FILE_MAX          48000
#endif
#define FS_RESERVE_BYTES        24576
#define EVENT_FLUSH_MS          60000UL
#define USERS_MAX               8
#define KEYPAD_LOCK_FAILS       5
#define KEYPAD_LOCK_MIN         5
#define TELEGRAM_BUTTON_SEC     180
#define SIP_SERVER_IP    ""
#define SIP_PORT         5060
#define SIP_USER         ""
#define SIP_PW           ""
#define SIP_CALLER_NAME  "Tueroeffner"
#define SIP_MAX_DIAL_SEC 15
#define SIP_REG_EXPIRES  120
#define SIP_REG_RETRY_SEC 10
#define SIP_BEEP_SECONDS 6
#define MQTT_SERVER            ""
#define MQTT_PORT              1883
#define MQTT_USER              ""
#define MQTT_PW                ""
#define MQTT_DISCOVERY_PREFIX  "homeassistant"
#define MQTT_CONNECT_TIMEOUT_MS 1000
#define MQTT_DNS_TIMEOUT_MS     5000
#define MQTT_RETRY_MAX_MS       300000UL
#define SCREEN_TIMEOUT_SECONDS 60
#define DEFAULT_DIAL_NR  ""
#define MAX_DIAL_LEN     20     // eine Nummer
#define MAX_DIAL_LIST    64     // Rufkette, z.B. "100, 101, 0171..."

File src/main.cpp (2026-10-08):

// SIP-Tueroeffner fuer ESP32 / ESP8266 - Start, Loop, WLAN/Ethernet und Selbstheilung.
// Uebersicht der Module: siehe app.h
#include "app.h"
#if defined(ESP32)
  #include <ESPmDNS.h>
  #include <esp_timer.h>
  #include <esp_task_wdt.h>
  #include <esp_system.h>
  #include <esp_heap_caps.h>
#else
  #include <ESP8266mDNS.h>
  #include <Ticker.h>
#endif
#include <ArduinoOTA.h>
#include <WiFiManager.h>
#if defined(USE_ETHERNET)
  #include <ETH.h>
#endif
#include <time.h>

String bootReason;
bool   portalActive = false;          // Einrichtungs-WLAN offen?
String myIpStr;                       // eigene IP (fuer SIP)

// WiFiManager schaltet beim Oeffnen des Portals eine nicht verbundene Station ab
// (_disableSTAConn; in 2.0.17 ohne Setter, aber protected). Beim spaeten Portal
// soll sie weiter verbinden -> kleine Unterklasse.
class DoorWiFiManager : public WiFiManager {
 public:
  void keepStation(bool keep) { _disableSTAConn = !keep; }
};

static DoorWiFiManager wm;
static bool     servicesUp    = false;   // Webserver, SIP, MQTT ... gestartet?
static bool     otaOn         = false;
static uint32_t restartAt     = 0;       // geplanter Neustart (nach der HTTP-Antwort)
static uint8_t  restartReason = 0;
static bool     wifiResetDue  = false;
static uint32_t netDownAt     = 0;       // seit wann ohne Verbindung (millis, 0 = verbunden)
static uint32_t wifiSavedAt   = 0;       // Zugangsdaten im Portal gespeichert (millis)
static uint32_t wifiRetryAt   = 0;       // letzter eigener Verbindungsversuch (millis)
static bool     wifiCreds     = false;   // WLAN-Zugangsdaten gespeichert? (je Versuch aktualisiert)
static bool     portalTried   = false;   // spaetes Einrichtungs-WLAN in dieser Offline-Phase schon offen
static bool     pwResetDone   = false;   // Notfall-Reset beim Start -> Mitteilung, sobald das Netz steht
#if defined(USE_ETHERNET)
static bool     ethStarted    = false;   // Ethernet-Treiber gestartet?
static uint32_t ethStuckAt    = 0;       // seit wann Link, aber keine IP (millis)
#endif

#if !defined(ESP32)
static Ticker            loopWdt;     // Loop-Watchdog (ESP32: Task-Watchdog)
static volatile uint32_t lastLoopAt = 0;
#endif

// ------------------------------------------------------------
//  Neustart mit Grund (ueberlebt den Neustart im RTC-Speicher)
// ------------------------------------------------------------
static const uint32_t RR_MAGIC = 0xA5C30000;

#if defined(ESP32)
RTC_NOINIT_ATTR uint32_t rtcReason;
void writeRestartReason(uint8_t r) { rtcReason = RR_MAGIC | r; }
static uint8_t readRestartReason() {
  uint32_t v = rtcReason;
  rtcReason = 0;
  return (v & 0xFFFF0000) == RR_MAGIC ? (uint8_t)(v & 0xFF) : RR_NONE;
}
#else
static const uint32_t RTC_REASON_BLOCK = 64;   // hinter dem vom OTA genutzten Bereich
void writeRestartReason(uint8_t r) {
  uint32_t v = RR_MAGIC | r;
  ESP.rtcUserMemoryWrite(RTC_REASON_BLOCK, &v, sizeof(v));
}
static uint8_t readRestartReason() {
  uint32_t v = 0;
  ESP.rtcUserMemoryRead(RTC_REASON_BLOCK, &v, sizeof(v));
  uint32_t zero = 0;
  ESP.rtcUserMemoryWrite(RTC_REASON_BLOCK, &zero, sizeof(zero));
  return (v & 0xFFFF0000) == RR_MAGIC ? (uint8_t)(v & 0xFF) : RR_NONE;
}
#endif

// Warum ist das Geraet zuletzt gestartet? (fuer die Weboberflaeche)
static String describeBootReason() {
  switch (readRestartReason()) {
    case RR_USER:       return "Neustart über die Weboberfläche";
    case RR_UPDATE:     return "Firmware-Update";
    case RR_WIFI_LOST:  return "Selbstheilung: WLAN war weg";
    case RR_LOW_HEAP:   return "Selbstheilung: Speicher knapp";
    case RR_WIFI_RESET: return "WLAN zurückgesetzt";
    case RR_RESTORE:    return "Sicherung eingespielt";
    case RR_NETWORK:    return "Netzwerk geändert";
    case RR_LOOP_WDT:   return "Watchdog (Programm hing)";
    default: break;
  }
#if defined(ESP32)
  switch (esp_reset_reason()) {
    case ESP_RST_POWERON:  return "Einschalten";
    case ESP_RST_EXT:      return "Reset-Taste";
    case ESP_RST_SW:       return "Software-Neustart";
    case ESP_RST_PANIC:    return "Absturz";
    case ESP_RST_INT_WDT:
    case ESP_RST_TASK_WDT:
    case ESP_RST_WDT:      return "Watchdog (Programm hing)";
    case ESP_RST_BROWNOUT: return "Unterspannung";
    default:               return "unbekannt";
  }
#else
  switch (ESP.getResetInfoPtr()->reason) {
    case REASON_DEFAULT_RST:      return "Einschalten";
    case REASON_EXT_SYS_RST:      return "Reset-Taste";
    case REASON_SOFT_RESTART:     return "Software-Neustart";
    case REASON_EXCEPTION_RST:    return "Absturz";
    case REASON_WDT_RST:
    case REASON_SOFT_WDT_RST:     return "Watchdog (Programm hing)";
    default:                      return "unbekannt";
  }
#endif
}

void restartNow(uint8_t reason) {
  stopBuzzer();
  saveState();
  writeRestartReason(reason);
  delay(50);
  ESP.restart();
}

void scheduleRestart(uint8_t reason, bool wifiReset) {
  restartReason = reason;
  wifiResetDue |= wifiReset;
  restartAt     = (millis() + 500) | 1;   // erst Antwort rausschicken; 0 = keiner geplant
}

void feedWatchdog() {
#if defined(ESP32)
  esp_task_wdt_reset();
#else
  lastLoopAt = millis();
  ESP.wdtFeed();
#endif
}

#if !defined(ESP32)
// Laeuft im Timer-Kontext: haengt die Loop (z.B. in einer Warteschleife mit
// delay()), greift der Hardware-Watchdog nicht -> hier neu starten
static void loopWdtCheck() {
  if (millis() - lastLoopAt > (uint32_t)LOOP_WATCHDOG_SEC * 1000UL) {
    writeRestartReason(RR_LOOP_WDT);
    ESP.reset();
  }
}
#endif

// Laufzeit in Sekunden (64 Bit, laeuft nicht nach 49 Tagen ueber)
uint32_t uptimeSeconds() {
#if defined(ESP32)
  return (uint32_t)(esp_timer_get_time() / 1000000ULL);
#else
  return (uint32_t)(micros64() / 1000000ULL);
#endif
}

// Groesster zusammenhaengender freier Block (Zerstueckelung des Speichers)
uint32_t maxFreeBlock() {
#if defined(ESP32)
  return heap_caps_get_largest_free_block(MALLOC_CAP_8BIT);
#else
  return ESP.getMaxFreeBlockSize();
#endif
}

bool otaActive() {
  return otaOn;
}

// ------------------------------------------------------------
//  WLAN und Netzdienste
// ------------------------------------------------------------
// Wird aufgerufen, sobald das WLAN-Einrichtungsportal (AP) startet
static void configModeCallback(WiFiManager *) {
  portalActive = true;
  String ip = WiFi.softAPIP().toString();
  logMsg("WLAN-Einrichtung offen: %s (%s), http://%s", WIFI_AP_NAME,
         apPw.length() ? "mit Passwort" : "OFFEN", ip.c_str());
  showPortalInfo(ip.c_str());
}

// Uhrzeit per NTP (laeuft im Hintergrund; bis dahin ist timeValid() false). Ohne
// Internet hilft das Gateway (Router/TK-Anlage bieten oft NTP an), dazu ein zweiter
// Pool-Server. sntp merkt sich nur Zeiger -> statische Puffer, beim Wechsel
// abwechselnd (der alte bleibt gueltig, bis sntp umgestellt ist).
static void startNtp() {
  static char    gwBuf[2][16];
  static uint8_t gwIdx = 0;
  const char *gw = nullptr;
  IPAddress g = netGateway();
  if ((uint32_t)g != 0) {
    gwIdx ^= 1;
    strlcpy(gwBuf[gwIdx], g.toString().c_str(), sizeof(gwBuf[gwIdx]));
    gw = gwBuf[gwIdx];
  }
#if defined(ESP32)
  configTzTime(TIME_ZONE, NTP_SERVER, gw, NTP_SERVER2);
#else
  configTime(TIME_ZONE, NTP_SERVER, gw, NTP_SERVER2);
#endif
}

// Einmalig, sobald das WLAN steht (und das Einrichtungsportal zu ist)
static void startServices() {
  myIpStr = netIP().toString();
  logMsg("%s verbunden, IP %s", netIsEthernet() ? "Ethernet" : "WLAN", myIpStr.c_str());

  // Modem-Sleep aus: sonst verschluckt der ESP Unicast-Pakete (Ping/HTTP)
#if defined(USE_ETHERNET)
#elif defined(ESP32)
  WiFi.setSleep(false);
#else
  WiFi.setSleepMode(WIFI_NONE_SLEEP);
#endif

  startNtp();

  // Name im Netz: http://tueroeffner.local
  if (MDNS.begin(HOSTNAME)) MDNS.addService("http", "tcp", 80);

  // OTA-Update aus PlatformIO (espota) nur mit Admin-Passwort - sonst koennte
  // jeder im Netz eine fremde Firmware aufspielen. Aenderungen gelten nach Neustart.
  if (webPw.length()) {
    ArduinoOTA.setHostname(HOSTNAME);
    ArduinoOTA.setPassword(webPw.c_str());
    ArduinoOTA.onStart([]() {
      stopBuzzer();
      stopChain();
      aSip.Hangup();
      saveState();   // Zaehler und Protokoll sichern
      writeRestartReason(RR_UPDATE);
    });
    ArduinoOTA.onProgress([](unsigned int, unsigned int) { feedWatchdog(); });
#if defined(ESP32)
    ArduinoOTA.setMdnsEnabled(false);   // mDNS laeuft schon
    ArduinoOTA.begin();
#else
    ArduinoOTA.begin(false);
#endif
    otaOn = true;
  } else {
    logMsg("OTA aus: erst ein Admin-Passwort setzen");
  }

  syslogBegin();
  mqttBegin();
  webBegin();
  initSip();
  homekitBegin();   // Apple Home (falls eingeschaltet)
  servicesUp = true;
  logMsg("Tueroeffner " FW_VERSION " bereit (%s)", bootReason.c_str());
  if (pwResetDone) {
    pwResetDone = false;
    queuePush(0, F("Notfall-Reset am Gerät: Passwörter gelöscht, DHCP aktiv"));
  }
}

// Zugangsdaten wurden im Portal gespeichert (WiFiManager-Rueckruf)
static void wifiSavedCallback() {
  wifiSavedAt = millis() | 1;
  wifiCreds   = true;
  logMsg("WLAN-Zugangsdaten gespeichert - verbinde");
}

#if !defined(USE_ETHERNET)
// Station mit den gespeicherten Zugangsdaten neu verbinden
static void staReconnect() {
  logMsg("WLAN: neuer Verbindungsversuch");
#if defined(ESP32)
  WiFi.disconnect();               // trennt eine halbe Verbindung (verbunden ohne IP)
#else
  WiFi.disconnect(false, false);   // ESP8266: WiFi.disconnect() loescht die Zugangsdaten!
#endif
  WiFi.begin();
  wifiRetryAt = millis();
}

// Portal zu (Zeit abgelaufen, "Exit" oder verbunden): Station sicher wieder starten.
// WiFiManager verbindet am Ende nur bei WL_IDLE_STATUS neu, Core 3.x meldet dann
// aber WL_DISCONNECTED - die Station bliebe sonst bis zur Selbstheilung untaetig.
static void portalClosed() {
  WiFi.setAutoReconnect(true);
  if (servicesUp) server.begin();   // eigene Weboberflaeche wieder auf Port 80
  displayDirty = true;              // Hinweis zur Einrichtung vom Display nehmen
  wifiCreds = wm.getWiFiIsSaved();
  if (!netUp() && wifiCreds) staReconnect();
}

// Bekanntes WLAN zu lange weg: Einrichtungs-WLAN oeffnen (z.B. neues Router-Passwort).
// Die Station bleibt an (AP+STA); neu verbunden wird nur im Minutentakt
// (wifiKeepTrying) - staendige Suchlaeufe machten das Einrichtungs-WLAN unbrauchbar.
static void openLatePortal() {
  logMsg("WLAN seit %u min weg - Einrichtungs-WLAN wird geoeffnet", (unsigned)WIFI_PORTAL_AFTER_MIN);
  if (servicesUp) server.stop();    // Port 80 gehoert solange dem Portal
  WiFi.setAutoReconnect(false);
  wm.keepStation(true);
  wm.setConfigPortalTimeout(WIFI_PORTAL_SECONDS);
  wm.startConfigPortal(WIFI_AP_NAME, apPw.length() ? apPw.c_str() : nullptr);
  portalActive = wm.getConfigPortalActive();
  if (!portalActive) {                // Start fehlgeschlagen
    WiFi.setAutoReconnect(true);
    if (servicesUp) server.begin();
  }
}

// WLAN weg: nach WIFI_RETRY_SEC und dann im selben Takt neu verbinden. Der Core 3.x
// verbindet bei manchen Trennungsgruenden nicht selbst neu (u.a. 202 AUTH_FAIL, wenn
// der Router nach einem Stromausfall noch startet). Nicht, solange das Portal
// gerade neue Zugangsdaten verbindet (wifiSavedAt).
static void wifiKeepTrying() {
  uint32_t now = millis();
  if (wifiSavedAt || now - netDownAt < (uint32_t)WIFI_RETRY_SEC * 1000UL ||
      now - wifiRetryAt < (uint32_t)WIFI_RETRY_SEC * 1000UL) return;
  wifiRetryAt = now;
  wifiCreds   = wm.getWiFiIsSaved();
  if (!wifiCreds) return;              // Ersteinrichtung: das Portal ist schon offen
  if (!portalActive && !portalTried && now - netDownAt >= (uint32_t)WIFI_PORTAL_AFTER_MIN * 60000UL) {
    portalTried = true;
    openLatePortal();
  }
  staReconnect();
}
#endif

// Verbindung ueberwachen: Dienste starten, bei neuer IP SIP neu anmelden
static void netLoop() {
#if defined(USE_ETHERNET)
  portalActive = false;
  bool connected = netUp();
#else
  bool wasPortal = portalActive;
  portalActive = wm.getConfigPortalActive();
  bool connected = netUp();
  if (wasPortal && !portalActive) portalClosed();   // Zeit abgelaufen oder "Exit"
#endif
  if (connected) {
    netDownAt   = 0;
    portalTried = false;
  } else if (!netDownAt) {
    netDownAt = millis() | 1;
  }

#if !defined(USE_ETHERNET)
  // Verbunden, aber Portal noch offen (z.B. erster Versuch nach dem Speichern
  // scheiterte, die automatische Wiederverbindung klappte dann doch) -> schliessen
  if (portalActive && connected) {
    logMsg("WLAN verbunden - Einrichtung wird beendet");
    wm.stopConfigPortal();
    portalActive = false;
    portalClosed();
  }
#endif
  // Gespeichert, aber keine Verbindung: der Verbindungsaufbau beim Start ist
  // zuverlaessiger als aus dem laufenden Portal heraus -> neu starten
  if (wifiSavedAt && !connected && millis() - wifiSavedAt > 45000UL) {
    logMsg("WLAN nach dem Speichern nicht verbunden -> Neustart");
    restartNow(RR_NETWORK);
  }
  if (connected) wifiSavedAt = 0;
#if !defined(USE_ETHERNET)
  if (!connected) wifiKeepTrying();
#endif

  if (portalActive || !connected) return;
  if (!servicesUp) {
    startServices();
    return;
  }
  String ip = netIP().toString();
  if (ip != myIpStr) {
    logMsg("Neue IP-Adresse %s (vorher %s) -> SIP neu anmelden", ip.c_str(), myIpStr.c_str());
    myIpStr = ip;
    initSip();
    syslogBegin();
    startNtp();                // Gateway (Zeitserver) kann sich geaendert haben
    mqttDiscoveryDue = true;   // configuration_url aktualisieren
  }
}

// Selbstheilung: Netzwerk zu lange weg oder Speicher knapp -> Neustart
static void selfHeal() {
#if defined(USE_ETHERNET)
  // Nur, wenn ein Link da ist, aber keine IP kommt (oder der Treiber nicht startete).
  // Bei gezogenem Kabel hilft kein Neustart (und Relais 2 an IO5 koennte zucken).
  if (netUp() || (ethStarted && !ETH.linkUp())) {
    ethStuckAt = 0;
  } else if (!ethStuckAt) {
    ethStuckAt = millis() | 1;
  } else if (millis() - ethStuckAt > (uint32_t)ETH_NO_IP_RESTART_MIN * 60000UL) {
    logMsg("Selbstheilung: Ethernet ohne IP-Adresse -> Neustart");
    restartNow(RR_WIFI_LOST);
  }
#else
  // Letzte Stufe nach den Verbindungsversuchen und dem Einrichtungs-WLAN. Ist das
  // Portal offen, erst nach der doppelten Zeit (vielleicht traegt gerade jemand das
  // WLAN ein) - ohne gespeicherte Zugangsdaten (Ersteinrichtung) gar nicht.
  uint32_t limit = (uint32_t)WIFI_LOST_RESTART_MIN * 60000UL;
  uint32_t down  = netDownAt ? millis() - netDownAt : 0;
  if (down > limit && (!portalActive || (down > 2 * limit && wifiCreds))) {
    logMsg("Selbstheilung: Netzwerk zu lange weg -> Neustart");
    restartNow(RR_WIFI_LOST);
  }
#endif
  if ((ESP.getFreeHeap() < MIN_FREE_HEAP || maxFreeBlock() < MIN_FREE_BLOCK) &&
      !aSip.IsBusy() && !buzzerActive) {
    logMsg("Selbstheilung: Speicher knapp (%u frei, Block %u) -> Neustart",
           (unsigned)ESP.getFreeHeap(), (unsigned)maxFreeBlock());
    restartNow(RR_LOW_HEAP);
  }
}

// ------------------------------------------------------------
//  Setup / Loop
// ------------------------------------------------------------
void setup() {
  // Als Erstes die Relais in Ruhelage (vor Serial und delay): Relais 2 liegt beim
  // WT32 auf IO5 (Strapping-Pin, Pull-up beim Reset), beim ESP8266 auf GPIO16 -
  // bis hier kann es kurz anziehen (Abhilfe siehe README "Relais beim Start")
  doorBegin();
#if defined(DOOR_ON_RX_PIN)
  Serial.begin(115200, SERIAL_8N1, SERIAL_TX_ONLY);   // RX wird zum Tuerkontakt
#else
  Serial.begin(115200);
#endif
  delay(100);
  bootReason = describeBootReason();
  Serial.printf("Start: %s\n", bootReason.c_str());

  settingsBegin();
  displayBegin();
  pushBegin();
  keypadBegin();
  logEvent(EV_BOOT, bootReason);
  pwResetDone = checkEmergencyReset();   // Mitteilung folgt, sobald das Netz steht

#if defined(USE_ETHERNET)
  // Ethernet (WT32-ETH01): kein WLAN, keine Einrichtung per Portal
  WiFi.mode(WIFI_OFF);
  ETH.setHostname(HOSTNAME);
  ethStarted = ETH.begin(ETH_PHY_LAN8720, ETH_PHY_ADDR_CFG, ETH_PHY_MDC_PIN, ETH_PHY_MDIO_PIN,
                         ETH_PHY_POWER_PIN, ETH_CLK_MODE_CFG);
  if (staticIp) ETH.config(ipAddr, ipGw, ipMask, ipDns);
  if (ethStarted) logMsg("Ethernet gestartet - warte auf Verbindung");
  else            logMsg("Ethernet startet nicht - Neustart in %d min", ETH_NO_IP_RESTART_MIN);
#else
  // WLAN: bekanntes Netz versuchen; sonst Einrichtungsportal, das NICHT blockiert -
  // Klingel, Taster und Summer funktionieren waehrenddessen weiter.
  WiFi.mode(WIFI_STA);
  wifiCreds = wm.getWiFiIsSaved();
  wm.setHostname(HOSTNAME);
  wm.setAPCallback(configModeCallback);
  wm.setSaveConfigCallback(wifiSavedCallback);
  wm.setConfigPortalBlocking(false);
  wm.setConfigPortalTimeout(wifiCreds ? WIFI_PORTAL_SECONDS : 0);
  // Mit gespeicherten Zugangsdaten kein Portal beim Start: nach einem Stromausfall
  // startet der Router oft langsamer als der ESP, und das Portal schaltet die
  // Station ab. netLoop verbindet weiter und oeffnet es erst spaet.
  wm.setEnableConfigPortal(!wifiCreds);
  wm.setConnectTimeout(20);
  // Im Portal nur WLAN-Auswahl anbieten (kein Firmware-Upload ohne Anmeldung)
  std::vector<const char *> menu = { "wifi", "exit" };
  wm.setMenu(menu);
  wm.setShowInfoUpdate(false);
  wm.setShowInfoErase(false);
  if (staticIp) wm.setSTAStaticIPConfig(ipAddr, ipGw, ipMask, ipDns);
  if (!wm.autoConnect(WIFI_AP_NAME, apPw.length() ? apPw.c_str() : nullptr)) {
    if (wifiCreds) logMsg("WLAN nicht verbunden - neuer Versuch im Hintergrund");
    else           logMsg("WLAN nicht verbunden - Einrichtung laeuft im Hintergrund");
  }
#endif

#if defined(ESP32)
  // Watchdog fuer die Loop: haengt sie laenger als LOOP_WATCHDOG_SEC -> Neustart
  esp_task_wdt_config_t wdt = { LOOP_WATCHDOG_SEC * 1000, 1, true };   // timeout, idle_core_mask, panic
  if (esp_task_wdt_reconfigure(&wdt) != ESP_OK) esp_task_wdt_init(&wdt);
  esp_task_wdt_add(nullptr);
#else
  lastLoopAt = millis();
  loopWdt.attach(5, loopWdtCheck);
#endif
}

void loop() {
  feedWatchdog();
#if !defined(USE_ETHERNET)
  wm.process();
#endif
  netLoop();
  if (servicesUp) {
    server.handleClient();
    if (otaOn) ArduinoOTA.handle();
#if !defined(ESP32)
    MDNS.update();
#endif
  }
  phoneLoop();
  doorLoop();
  keypadLoop();
  homekitLoop();
  mqttLoop();
  pushLoop();
  settingsLoop();
  selfHeal();

  // Geplanter Neustart (nach Update, Neustart-Button, WLAN-Reset, Sicherung, Netzwerk)
  if (restartAt && (int32_t)(millis() - restartAt) >= 0) {
#if !defined(USE_ETHERNET)
    if (wifiResetDue) wm.resetSettings();
#endif
    restartNow(restartReason);
  }
}

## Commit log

2026-10-01 SIP: PCMA (A-law) anbieten, Codec und DTMF-PT aus Antwort übernehmen
    Viele europäische Anlagen lehnen reines PCMU mit 488 Not Acceptable ab.
    Das SDP-Angebot enthält jetzt PCMA und PCMU; der Piepton wird im von der
    Gegenstelle gewählten Codec kodiert, der telephone-event Payload Type wird
    aus der Antwort gelesen statt fest 101.
2026-10-02 Anmeldung und Bestätigen
2026-10-08 Schaltung von Tastendruck
    [esp_dooropen.kicad_pcb, esp_dooropen.kicad_sch, stueckliste.csv]
2026-10-08 Härtung
    [esp_dooropen.kicad_pcb, esp_dooropen.kicad_sch]
